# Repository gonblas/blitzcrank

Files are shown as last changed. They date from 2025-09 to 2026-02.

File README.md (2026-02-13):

Banner para Blitzcrank

# Blitzcrank

<p align="center">
  
  
</p>

## Descripción del proyecto

El proyecto **Blitzcrank** es un prototipo de **garra robótica móvil** diseñado para desplazarse en dos ejes (X e Y) mediante un sistema de rieles. Sobre este plano de movimiento, la garra puede **subir, bajar, abrir y cerrar**, lo que le otorga la capacidad de manipular objetos livianos dentro de un área determinada. El control se realiza manualmente a través de un **joystick de efecto Hall** y un conjunto de botones que permiten al usuario interactuar de manera sencilla e intuitiva.

Más allá de su valor como ejercicio técnico, el prototipo puede servir como base para múltiples aplicaciones: desde la simulación de procesos de **transporte y manipulación de piezas** hasta escenarios lúdicos como las clásicas máquinas de garras o sistemas recreativos de precisión, por ejemplo, un robot capaz de jugar al ajedrez moviendo las piezas en el tablero. De esta manera, Blitzcrank demuestra cómo la **tecnología robótica** puede adaptarse tanto a la **experimentación educativa** como a la **innovación aplicada** en proyectos más complejos.

<details>
  <summary><i>Objetivos del proyecto</i></summary>

  - **Objetivos primarios:**

    Se detallan a continuación aquellos objetivos de carácter obligatorio, necesarios para la validación del proyecto.

    - Implementar un sistema de rieles que permita el desplazamiento de la garra en los ejes X e Y.
    - Incorporar un mecanismo que posibilite el movimiento vertical de la garra para subir y bajar.
    - Desarrollar un sistema de control manual que garantice un manejo sencillo e intuitivo.
    - Integrar un actuador que permita abrir y cerrar la garra para tomar y soltar objetos.

  - **Objetivos secundarios:**

    A continuación se detallan aquellos objetivos de carácter opcional, sujetos a tiempo, materiales y costos disponibles.

    - Adaptar el sistema para manipular piezas de ajedrez en un tablero, garantizando precisión en la colocación.
    - Implementar un módulo de visión artificial que permita identificar la posición de las piezas en el tablero.
    - Integrar un algoritmo de inteligencia artificial que tome decisiones de juego y guíe automáticamente los movimientos de la garra.
    - Implementar una interfaz web que permita el manejo de la garra.

</details>

<details>
  <summary><i>Requerimientos del proyecto</i></summary>

  ##### Requerimientos Funcionales

  - **Requerimientos de Hardware:**

    - Debe contar con una interfaz física para mover la garra.
      - El sistema debe incluir unos botones dedicados al ascenso y descenso de la garra.
      - El sistema debe incluir un potenciómetro dedicado a la apertura y cierre de la garra.
      - El sistema debe incorporar un controlador para manejar los movimientos de la garra en los ejes X e Y.
      - El sistema debe incorporar un botón para manejar el cambio de modo físico y remoto.
    - Movimiento preciso de la garra.
      - El sistema de rieles debe permitir el movimiento de la garra en dos ejes cartesianos (X e Y), con un área mínima de trabajo de 15 cm x 15 cm.
      - El eje Z debe recorrer verticalmente al menos 5 cm para tomar y elevar piezas.
      - Se deben utilizar motores paso a paso para garantizar la posición exacta de la garra.
      - La garra debe ser capaz de levantar objetos de 50 gramos.
    - Todos los componentes deben estar ensamblados con fines de obtener un único sistema final compacto.

  - **Requerimientos de Software:**

    - Se debe desarrollar una interfaz de usuario capaz de controlar el sistema.
      - Desarrollar una interfaz que permita controlar manualmente la garra.
      - Implementar una interfaz web que permita seleccionar el modo de operación.
      - La interfaz debe ser intuitiva y clara, mostrando el estado del sistema y los errores en caso de que ocurran.
    - El software debe gestionar los límites de movimiento, deteniendo la garra para evitar daños mecánicos.

  ##### Requerimientos no funcionales

  Estos requerimientos no afectan en la funcionalidad del proyecto, por lo cual no se ve necesidad de hacer particular énfasis en la validación, pero que sí han sido tenidos en cuenta en el desarrollo.

  - Plataforma y desarrollo.
    - Utilizar una placa EDU-CIAA-NXP como centro de control del sistema, basada en el microcontrolador NXP LPC 4337.
    - Todo el firmware del EDU-CIAA debe ser desarrollado en lenguaje C.
  - Tiempo de ejecución: 16 semanas.
  - Presupuesto total de 600.000 ARS.
  - Documentación.
    - Documentar detalladamente el proceso de ensamblado del sistema.
    - Documentar el desarrollo del firmware, incluyendo rutinas de control e inicialización.
    - Documentar el diseño del esquemático y PCB, incluyendo conexiones, componentes y disposición de pines.
  - Garantizar la seguridad del usuario durante la operación del sistema, incluyendo protecciones físicas.

</details>

<details>
  <summary><i>Diagrama en bloques del sistema</i></summary>
  
  Diagrama en bloques inicial

</details>

<details>
  <summary><i>Tecnologías utilizadas</i></summary>
  <ol>

  <li>Hardware</li>
    <ul>
      <li>EDU-CIAA-NXP (LPC4337): placa central de control del sistema</li>
      <li>ESP-WROOM-32: módulo Wi-Fi para control remoto e interfaz web</li>
      <li>Motores paso a paso Nema17: movimiento en ejes X e Y</li>
      <li>Drivers DRV8825: control de motores paso a paso</li>
      <li>Motor DC GA12N20 + Driver DRV8833: accionamiento de polea</li>
      <li>Servomotor TowerPro MG90s: apertura y cierre de la garra</li>
      <li>Joystick analógico SYSPORT: control de movimiento X-Y</li>
      <li>Potenciómetro 10k: control analógico de la garra</li>
      <li>Fuente 12V 5A + Step Down XL4005: alimentación del sistema</li>
    </ul>

  <li>Firmware</li>
    <ul>
      <li>Lenguaje C para el firmware de la EDU-CIAA-NXP</li>
      <li>C++ con Arduino Framework para el firmware del ESP32</li>
      <li>PlatformIO como entorno de desarrollo del ESP32</li>
      <li>Comunicación UART entre EDU-CIAA y ESP32</li>
    </ul>

  <li>Interfaz web (ESP32)</li>
    <ul>
      <li>HTML, CSS y JavaScript servidos desde SPIFFS</li>
      <li>ESPAsyncWebServer para el servidor web embebido</li>
      <li>WebSockets para comunicación en tiempo real</li>
    </ul>

  <li>Diseño y fabricación</li>
    <ul>
      <li><a href="https://www.kicad.org/">KiCad</a>: diseño de esquemáticos y PCB</li>
      <li><a href="https://www.autodesk.com/products/fusion-360/overview">Fusion 360</a>: modelado 3D de estructura y garra</li>
      <li><a href="https://ultimaker.com/es/software/ultimaker-cura/">UltiMaker Cura</a>: preparación de piezas para impresión 3D</li>
    </ul>

  </ol>
</details>

---

## Materiales

| Componente | Cantidad | Función |
| --- | --- | --- |
| EDU-CIAA-NXP | 1 | Placa central que coordina motores, sensores y comunicación |
| ESP-WROOM-32 38 PINES | 1 | Control inalámbrico mediante Wi-Fi, interfaz web remota |
| Potenciómetro 10k Lineal 16mm | 1 | Entrada analógica para apertura de garra |
| Push Button Tact Switch 6x6mm | 3 | Entrada digital para abrir/cerrar garra |
| Joystick analógico SYSPORT | 1 | Control principal en ejes X e Y con pulsador integrado |
| Motor DC GA12N20 | 1 | Motorreductor para accionar polea |
| Driver Motor DC Puente H DRV8833 | 1 | Control de motor DC, inversión de giro y regulación por PWM |
| Servomotor TowerPro MG90s | 1 | Apertura y cierre de la garra |
| Motor paso a paso Nema17 17HS3404N | 2 | Movimiento de ejes X-Y |
| Driver DRV8825 | 2 | Controlador de motores paso a paso |
| Fuente de 12V 5A SIMALED LCS-1721-M1 | 1 | Fuente de alimentación externa para todo el sistema |
| Módulo Step Down XL4005 | 1 | Transformador de tensión |

---

## Diseño 3D

<details>
  <summary>Sistema completo</summary>
  <p align="center">
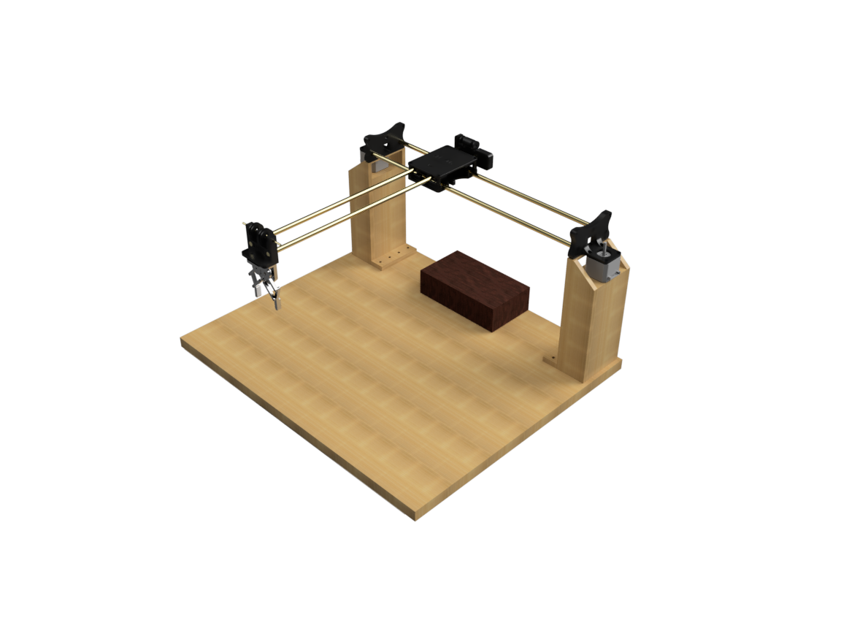
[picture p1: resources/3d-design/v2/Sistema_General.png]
    
  </p>
</details>

<details>
  <summary>Garra</summary>
  <p align="center">
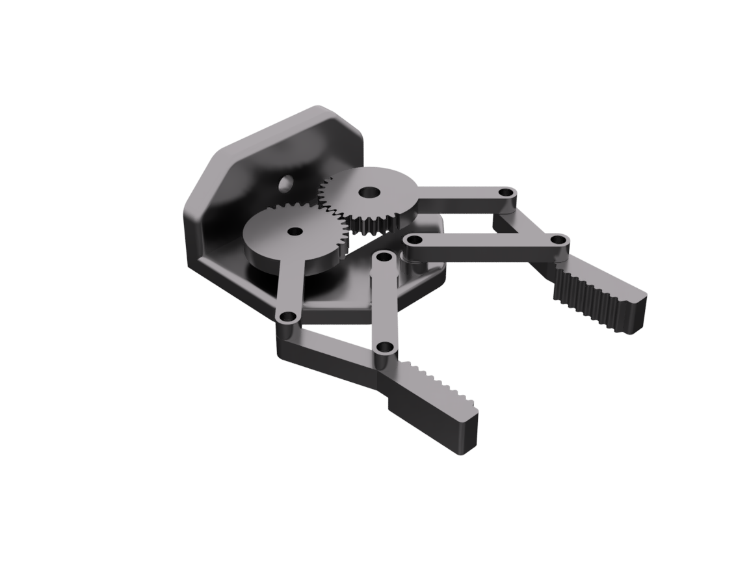
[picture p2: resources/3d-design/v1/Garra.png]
    
  </p>
</details>

<details>
  <summary>Sistema de poleas</summary>
  <p align="center">
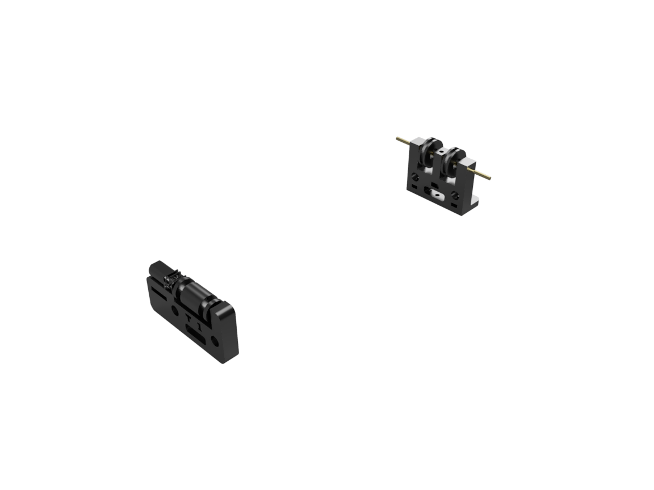
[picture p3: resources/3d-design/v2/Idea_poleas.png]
    
  </p>
</details>

<details>
  <summary>Controlador</summary>
  <p align="center">
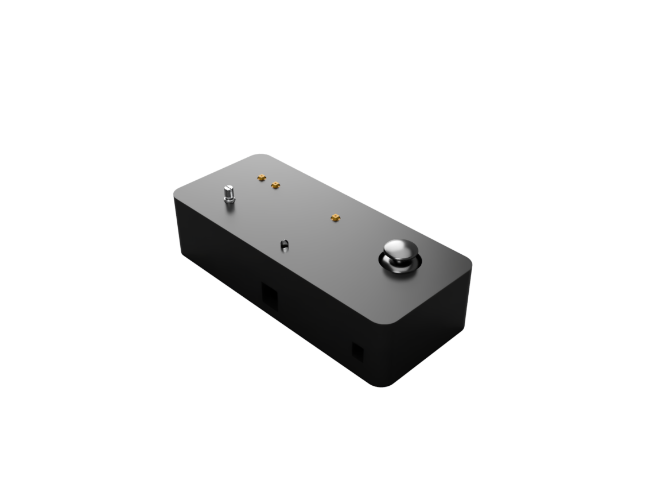
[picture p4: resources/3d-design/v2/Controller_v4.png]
    
    
  </p>
  <p align="center">
    
  </p>
</details>

<details>
  <summary>Eje Y</summary>
  <p align="center">
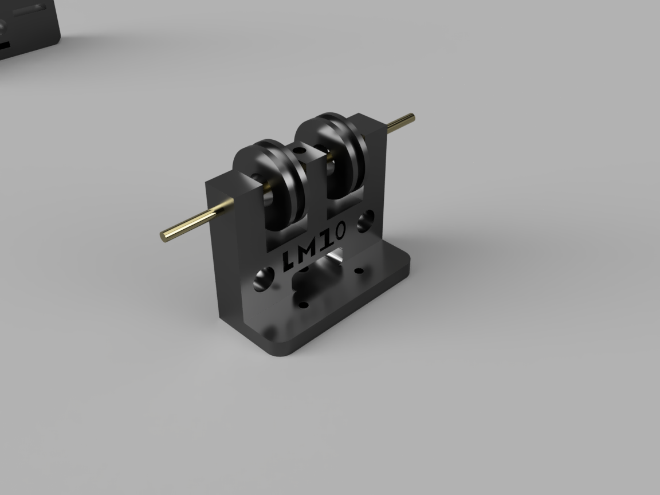
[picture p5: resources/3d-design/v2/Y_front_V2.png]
    
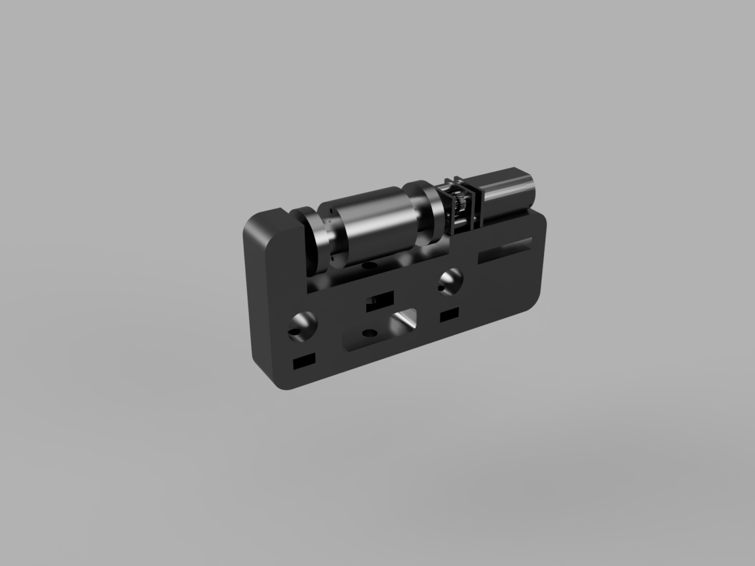
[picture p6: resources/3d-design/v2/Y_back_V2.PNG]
    
  </p>
</details>

---

## PCB

<details>
  <summary>Diseño del PCB</summary>
  <p align="center">
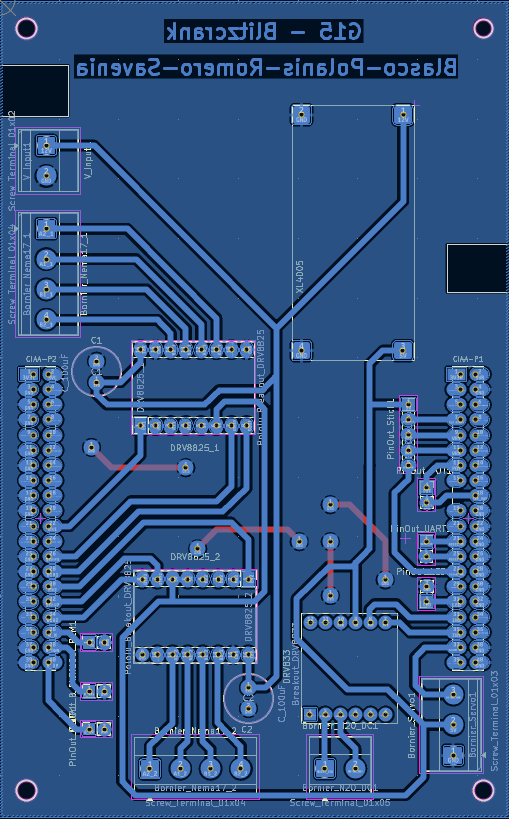
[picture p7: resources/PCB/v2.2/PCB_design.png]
    
  </p>
</details>

<details>
  <summary>PCB 3D</summary>
  <p align="center">
    
  </p>
</details>

<details>
  <summary>PCB Construído</summary>
  <p align="center">
    
    
  </p>
</details>

---

## Estructura del Proyecto

```
Blitzcrank/
│
├── build/                        # Archivos de compilación
├── docs/                         # Documentación y diagramas del proyecto
├── firmware/                     # Directorio principal del firmware
│   ├── mainboard/                # Firmware del controlador principal (LPC4337)
│   │   ├── .settings/            # Configuración del entorno de desarrollo
│   │   ├── app/                  # Aplicación principal del firmware
│   │   │   ├── drivers/          # Drivers de hardware (UART, SPI, I2C, GPIO, etc.)
│   │   │   ├── inc/              # Archivos de encabezado propios del proyecto
│   │   │   ├── out/              # Archivos de salida (build temporal, objetos, etc.)
│   │   │   └── src/              # Código fuente de la aplicación
│   │   │       └── main.c        # Punto de entrada del firmware
│   │   │
│   │   ├── examples/             # Ejemplos de uso de las distintas librerías
│   │   ├── libs/                 # Librerías externas o módulos reutilizables
│   │   ├── scripts/              # Scripts auxiliares para automatizar tareas del proyecto
│   │   ├── test/                 # Código de pruebas del hardware y validación de módulos
│   │   ├── .cproject             # Configuración del compilador (Eclipse)
│   │   ├── .gitignore            # Archivos ignorados por Git
│   │   ├── .project              # Configuración del proyecto (Eclipse)
│   │   ├── .travis.yml           # Integración continua (Travis CI)
│   │   ├── board.mk              # Configuración específica de la placa (paths, flags, etc.)
│   │   ├── LICENSE               # Licencia del proyecto
│   │   ├── Makefile              # Archivo principal de construcción del proyecto
│   │   ├── program.mk            # Reglas de programación/flasheo del firmware
│   │   ├── README.md             # Documentación general del firmware principal
│   │
│   └── esp-32/                   # Firmware del módulo ESP32
│       ├── src/                  # Código fuente principal (main.cpp)
│       │
│       ├── lib/                  # Librerías locales del proyecto
│       │   ├── WiFiManager/      # Manejo de conexión Wi-Fi y modo AP
│       │   ├── SpiffsManager/    # Gestión del sistema de archivos SPIFFS (lectura/escritura)
│       │   ├── Routes/           # Ruteo de peticiones HTTP y manejo del servidor web
│       │   └── UARTManager/      # Comunicación serial UART y sincronización de datos con la web
│       │
│       ├── data/                 # Archivos de la interfaz web que se suben al SPIFFS
│       │   ├── index.html
│       │   ├── style.css
│       │   └── script.js
│       │
│       ├── include/  
│       ├── lib/                  # Librerías externas (ESPAsyncWebServer, etc.)
│       ├── platformio.ini        # Configuración de PlatformIO
│       └── test/                 # Pruebas específicas del ESP
│
├── hardware/                     # Diseños de PCB, Esquemáticos, Diseños 3D
│   ├── pcb/                      # Diseños de PCB
│   ├── 3d-design/                # Diseños 3D
│   └── schematic/                # Circuitos esquemáticos
│
├── resources/                    # Documentación técnica y de apoyo
│   ├── 3d-design/                # Imágenes de los diseños 3D
│   ├── datasheets/               # Datasheets de los componentes utilizados
│   ├── manuals/                  # Manuales de módulos, sensores, devkits, etc.
│   ├── notes/                    # Apuntes técnicos, application notes, cálculos útiles
│   └── schematics/               # Esquemas de conexión, wiring y diagramas eléctricos
│
├── .clang-format                 # Configuración de estilo de código
├── .gitignore                    # Archivos ignorados por Git
├── LICENSE                       # Licencia del proyecto
├── README.md                     # Archivo actual
└── STYLE_GUIDE.md                # Convenciones de estilo del proyecto
```

Para ver las convenciones de nombres y estilo de código, consultar [STYLE_GUIDE.md](./STYLE_GUIDE.md)

---

## Flujo de funcionamiento del sistema

<p align="center">
  <a href="https://www.youtube.com/@BlitzcrankG15">
    
  </a>
</p>

<p align="center">
  <a href="https://www.youtube.com/watch?v=uDqSojhFeGg">
    
  </a>
  <a href="https://www.youtube.com/watch?v=HAsxXd6xPtw">
    
  </a>
</p>

---

## Autores

<ul>
  <li>
    <a href="https://www.linkedin.com/in/gonblas/">
      
    </a>
    <a href="https://github.com/gonblas">
      
    </a>
    <strong>Blasco, Gonzalo</strong>
    <br clear="right"/>
  </li>

  <li>
    <a href="https://www.linkedin.com/in/ivanpolanis/">
      
    </a>
    <a href="https://github.com/ivanpolanis">
      
    </a>
    <strong>Polanis, Iván Valentín</strong>
    <br clear="right"/>
  </li>

  <li>
    <a href="https://www.linkedin.com/in/mateo-romero-dev/">
      
    </a>
    <a href="https://github.com/mateoromero-dev">
      
    </a>
    <strong>Romero, Mateo</strong>
    <br clear="right"/>
  </li>

  <li>
    <a href="https://www.linkedin.com/in/manuel-savenia-b38639363/">
      
    </a>
    <a href="https://github.com/manuSavenia">
      
    </a>
    <strong>Savenia, Manuel</strong>
    <br clear="right"/>
  </li>
</ul>

## Coordinador

<ul>
  <li>
    <a href="https://www.linkedin.com/in/joaquín-chanquía-a747a1291/">
      
    </a>
    <a href="https://github.com/joacochanquia">
      
    </a>
    <strong>Joaquín Chanquía</strong><br />
    <em>Ayudante – Taller de Proyecto I</em>
    <br clear="right"/>
  </li>
</ul>

---

## Licencia

Este proyecto se distribuye bajo la licencia [GPL](LICENSE).

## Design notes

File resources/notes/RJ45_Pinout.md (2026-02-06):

# Controller RJ-45 Pinout

| Color | Nombre (es) | Función / Notas | Pin PONCHO |
| --- | --- | --- | --- |
| 🔵 Azul | Joystick Y | Señal analógica del eje Y del joystick | VRY |
| 🟡 Amarillo | Joystick X | Señal analógica del eje X del joystick | VRX |
| 🟠 Naranja  | Bit de conexión | Línea digital para handshake / estado de conexión | ON |
| 🟢 Verde | LED | Alimentación / señal para LED indicador | L |
| 🟣 Violeta  | Potenciómetro | Entrada analógica de potenciómetro | POT |
| ⚫ Negro | Botón Down | Pulsador para acción "bajar" | DWN(S) |
| ⚪ Blanco | Botón Switch Mode | Pulsador para cambiar modo | MD |
| ◻️ Gris | Botón Up | Pulsador para acción "subir" | UP |

# USB

| Color | Pin PONCHO |
| --- | --- |
| Naranja | 5V+ |
| Negro | BTN_DWN |

Notas:

- Verifica con un multímetro/continuidad antes de conectar si no estás seguro del cableado.

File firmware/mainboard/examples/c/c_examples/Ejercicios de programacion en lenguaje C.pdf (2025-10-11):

# Ejercicios de programación en lenguaje C

Estos programas pueden probarlos primero en la PC usando http://cpp.sh/ o http://onlinegdb.com/ (elegir lenguaje C y presionar run).

Los usuarios de Linux Pueden usar la plantilla de Embedded IDE "gcc-exec" y probarlo en sus propias PC. Los de Windows hay que instalar más herramientas para compilar C para PC asi que usen el compilador on line.

# Ejercicios básicos de C

### 1. Suponga que una variable declarada como

uint16_t temperatura_sensor;

contiene la salida de un sensor de temperatura con una resolución de 10 bits y un rango de 0°C a 800 °C.Esto es, el valor temperatura_sensor = 0 corresponderá a la medida de 0 °C mientras que temperatura_sensor = 1023 corresponderá a la medida de 800 °C.

Sería deseable disponer de una nueva variable: temperatura_grados que almacene la medida directamente en grados para poder procesarla y mostrarla por UART directamente.

a. Escriba el programa que transforma el valor entregado por el sensor a grados Celcius y lo almacena en temperatura_grados.
b. Pruebe distintos valores de temperatura_sensor y conviértalos a temperatura_grados.

Imprima los valores por UART. Por ejemplo
temperatura_sensor = 0 --> temperatura_grados = 0°C temperatura_sensor = 128 --> temperatura_grados = 100°C temperatura_sensor = 512 --> temperatura_grados = 400°C temperatura_sensor = 1023 --> temperatura_grados = 800°C
c. Sabiendo que el rango de la variable temperatura_sensor admite valores menores que 0 y mayores que 1023, busque una solución para detectar estos casos e indicarle al usuario de que hay una falla en el sensor.

2. Operadores.
a. Indique el resultado de las siguientes expresiones:

(1 >2) || (1<2)
(1>2) && 3
1 + 2 / 3 * 4 – 5
b. Considerando: int a=1, b=2, c=3; diga cuánto valen cada una de las siguientes expresiones:

a<b && c<b
a<b && c
a<=c || b>c
a!=b-1 || b>2 || a+c>2

### 3. Bucles 1

Realice una tabla utilizando printf() en la UART con el siguiente encabezado:

x | x al cuadrado | x al cubo
a) complete con valores enteros de x entre 0 y 20 utilizando un bucle while.
b) complete con valores enteros de x entre 0 y 20 utilizando un bucle for.
c) complete con valores reales de x entre 0 y 10, con incrementos de 0.5 utilizando un bucle while.
d) complete con valores reales de x entre 0 y 10, con incrementos de 0.5 utilizando un bucle for.

Nota: utilice el caracter '\t' que realiza la función de tab para ordenar correctamente las tablas en la Terminal. Revisar si lo soporta la terminal serie que utiliza.

### 4. Bucles 2

Realice los siguientes "dibujos" en la Terminal Serie parametrizados según el valor de N y M, según corresponda (usar #define para N y M).

a)
*
*
*
*
(N filas)

b)
*
**
***
****
(N filas)

c)
1
22
333
4444
(N filas)

d)
1
12
123
1234
(N filas)

e)
*******
*******
*******
(N filas x M columnas)
f) El cuadrado:
*******
* | *
* | *
*******
(N filas x M columnas)
g) El triángulo:
*******
* *
* *
*
(N filas, con N impar)

# Ejercicios de C con Arreglos (vectores o matrices)

Resolver los siguientes utilizando índices de arreglos

5. Realice nuevamente el ejercicio 3 pero esta vez utilice los arreglos x[], x2[] y x3[] para almacenar primero los valores correspondientes de x, x al cuadrado y x al cubo, respectivamente.
Luego repita la tabla a partir de los arreglos anteriores.
6. Dado un arreglo de 40 caracteres que contiene un string a elección, realizar un programa que cuente la cantidad de caracteres y la cantidad de mayúsculas del string e imprima el resultado usando índice para recorrer el arreglo.
7. Realice un programa que copie el string contenido en el arreglo Texto1 al arreglo Texto2 cambiando todas las letras mayúsculas por minúsculas y luego imprima un string debajo del otro en pantalla. Ambos arreglos son de 30 caracteres.

### 8. Dado cuatro arreglos de 20 caracteres: Texto1, Mayu, Minu y Noletra, realizar un

programa que a partir del string a elección almacenado en Texto1, genere 3 strings:
Uno en Mayu con todas las mayúsculas, otro en Minu todas las minúsculas y otro en Noletra con todos los caracteres que no sean letras.
Finalmente deberá imprimir los 4 strings en líneas sucesivas dentro de llaves o corchetes.
9. Dados dos arreglos de 50 caracteres Tx1 y Tx2 que contiene strings a elección, realizar un programa que imprima los strings y luego concatene el string contenido en Tx2 al de Tx1. Finalmente Imprimir el string resultante contenido en Tx1. Todos los strings deberán imprimirse dentro de llaves o corchetes.

### 10. Dado un arreglo de 30 caracteres que contiene un string a elección, realizar un

programa que cuente e imprimir a la cantidad de vocales de cada tipo. Usar la estructura switch.

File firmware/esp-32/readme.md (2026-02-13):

# Firmware ESP32 - Control Web de Garra

Este firmware permite el control remoto de una garra robótica a través de una interfaz web. El sistema crea un servidor web en el ESP32 que sirve una página de control desde la cual se puede manejar la garra de forma inalámbrica.

## Estructura del Proyecto

```
esp-32/                       # Firmware del módulo ESP32
├── src/                      # Código fuente principal (main.cpp)
│   └── main.cpp
│
├── lib/                      # Librerías locales del proyecto
│   ├── WiFiManager/          # Manejo de conexión Wi-Fi y modo AP
│   │   └── config.h
│   ├── SpiffsManager/        # Gestión del sistema de archivos SPIFFS (lectura/escritura)
│   ├── Routes/               # Ruteo de peticiones HTTP y manejo del servidor web
│   └── UARTManager/          # Comunicación serial UART y sincronización de datos con la web
│
├── data/                     # Archivos de la interfaz web que se suben al SPIFFS
│   ├── index.html
│   ├── style.css
│   └── script.js
│
├── platformio.ini            # Configuración del entorno PlatformIO (placa, librerías, etc.)
├── readme.md                 # Este archivo
└── test/                     # Pruebas específicas del firmware (unit tests o integración)
```

## Requisitos

Para usar este firmware necesitas tener instalado **PlatformIO** en Visual Studio Code.

### Instalación de PlatformIO

1. Abre Visual Studio Code
2. Ve a la pestaña de Extensiones (Ctrl+Shift+X)
3. Busca "PlatformIO IDE"
4. Instala la extensión oficial

**Enlace directo**: [PlatformIO IDE Extension](https://marketplace.visualstudio.com/items?itemName=platformio.platformio-ide)

## Configuración WiFi

El sistema puede funcionar en dos modos:
- **Modo Access Point (AP)**: El ESP32 crea su propia red WiFi
- **Modo Cliente**: El ESP32 se conecta a una red WiFi existente

Para configurar el modo de funcionamiento, edita el archivo `lib/WiFiManager/config.h` donde puedes establecer:
- SSID y contraseña de la red WiFi
- Modo de operación (AP o Cliente)

## Pasos para Probar el Funcionamiento

1. **Abrir PlatformIO**: Ve a la extensión de PlatformIO en VS Code
2. **Subir archivos web**: En la pestaña **Platform** → hacer clic en **Upload Filesystem Image**
3. **Limpiar proyecto**: En la pestaña **General** → hacer clic en **Full Clean**
4. **Compilar**: En la pestaña **General** → hacer clic en **Build**
5. **Subir y monitorear**: En la pestaña **General** → hacer clic en **Upload and Monitor**

> **Nota**: El **Full Clean** solo es necesario la primera vez para evitar errores de compilación.

## Acceso a la web

Para utilizar el control remoto, se deben seguir los siguientes pasos:

1. **Conectarse a la red Wi-Fi del sistema:**

   Desde una computadora o dispositivo móvil, conectarse a la red Wi-Fi generada por el ESP32 con los siguientes datos:

   - **Nombre de red (SSID):** `blitzcrank`
   - **Contraseña:** `garra12345`

2. **Acceder a la interfaz web:**

   Una vez establecida la conexión Wi-Fi, abrir un navegador web y acceder a la siguiente dirección: [http://192.168.4.1](http://192.168.4.1)

   Al ingresar esta dirección, se cargará la página web correspondiente al control remoto del sistema.

## Flujo de Trabajo para Modificaciones

### Solo cambios en archivos web (data/)
- Ejecutar únicamente: **Upload Filesystem Image**

### Solo cambios en código (src/, lib/)
- Ejecutar: **Build** → **Upload and Monitor**

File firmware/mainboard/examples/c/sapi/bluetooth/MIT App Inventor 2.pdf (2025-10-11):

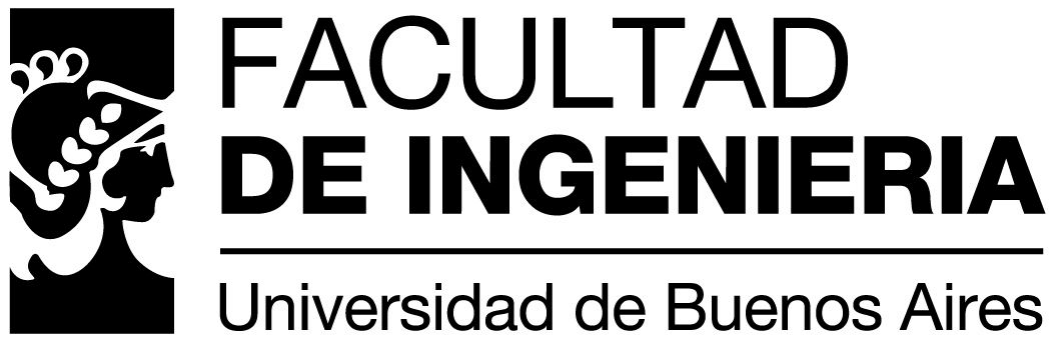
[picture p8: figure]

## Carrera de Especialización en Sistemas Embebidos (CESE) de la FI-UBA

### 8. Protocolos de comunicación en Sistemas Embebidos

MIT App Inventor 2

Profesores:
- Esp. Ing. Eric Pernia.
- Dr. Ing. Pablo Gómez.

“MIT App Inventor 2”
por Esp. Lic. Agustin Bassi, se distribuye bajo una Licencia Creative Commons Atribución-CompartirIgual 4.0 Internacional.

## Licencia

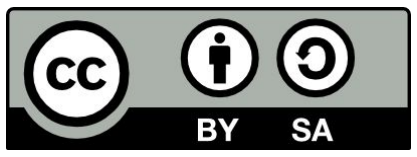
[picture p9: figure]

Para realizar una aplicación en Android para probar la comunicación con la EDU-CIAA-NXP vamos a utilizar APP Inventor, que es una herramienta sencilla para desarrollar aplicaciones Android evitando utilizar las herramientas típicas las cuales consisten en lenguaje de programación Java, XML, emulación virtual y el entorno de desarrollo Android Studio. (https://developer.android.com/studio/)

APP Inventor es un desarrollo de Google que permite programar aplicaciones para Android mediante programación gráfica. Posteriormente, el proyecto fue retomado por el MIT y ahora es conocido como MIT App Inventor 2.

MIT App Inventor 2 es una herramienta para desarrollo on line por lo que requiere conexión permanente a Internet.

## Introducción

Paso 1

Tener una cuenta en Gmail
En https://accounts.google.com/ se puede crear una cuenta. Si ya se tiene cuenta, este paso es innecesario.

Paso 2

Ir a la página de MIT App Inventor 2
Dirigirse a http://appinventor.mit.edu/explore/front.html Allí inicia todo!

## Configuración APP Inventor 2

Paso 3 - Iniciar MIT App Inventor

Dirigirse a http://appinventor.mit.edu/explore/index-2.html y dar clic en “Create Apps”.

## Configuración APP Inventor 2

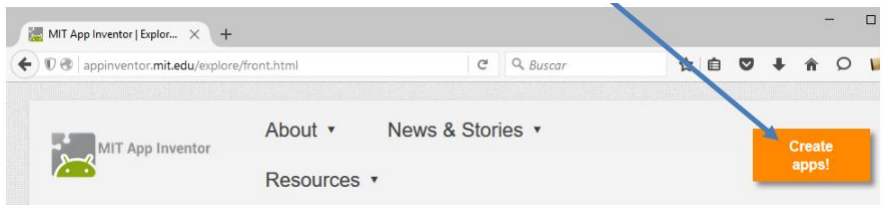
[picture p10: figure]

Paso 4 - Acceder a APP Inventor 2 con la cuenta de Google.

## Configuración APP Inventor 2

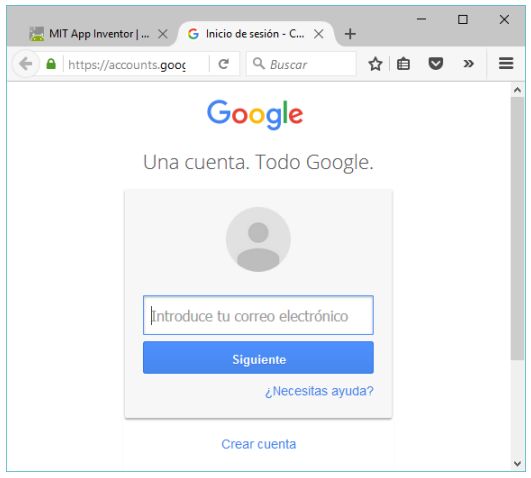
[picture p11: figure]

Paso 5 - Pantalla de inicio APP Inventor.

Al ser la primera vez, no se tienen proyectos en la cuenta.

## Configuración APP Inventor 2

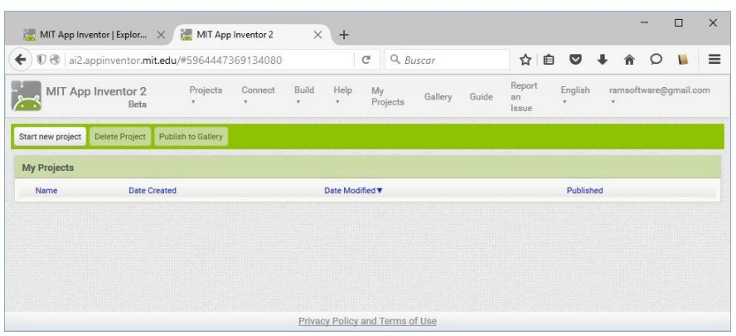
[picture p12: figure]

Paso 6 - Cambiar idioma en APP Inventor

Si es de preferencia, cambiar el idioma a Español.

## Configuración APP Inventor 2

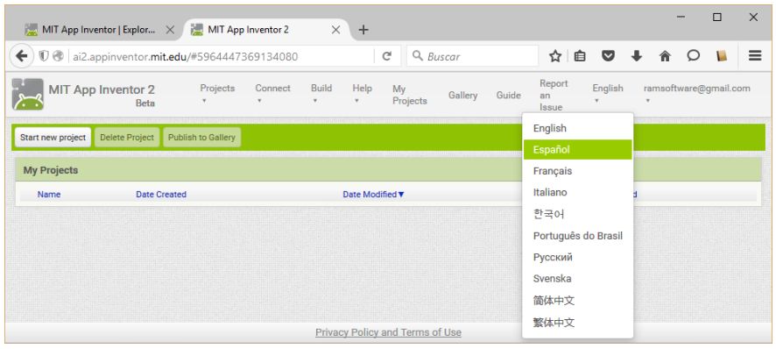
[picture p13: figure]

Paso 7 - Aceptar la información.
Tildar la opción “Do not show Again” para que no vuelva a aparecer este cartel nuevamente.

## Configuración APP Inventor 2

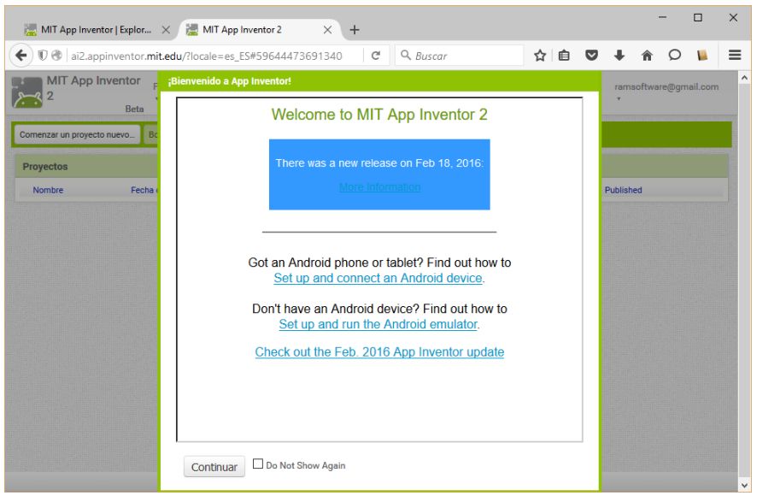
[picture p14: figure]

Paso 8 - Fin de la configuración

Bienvenido a APP Inventor 2 !!!

## Configuración APP Inventor 2

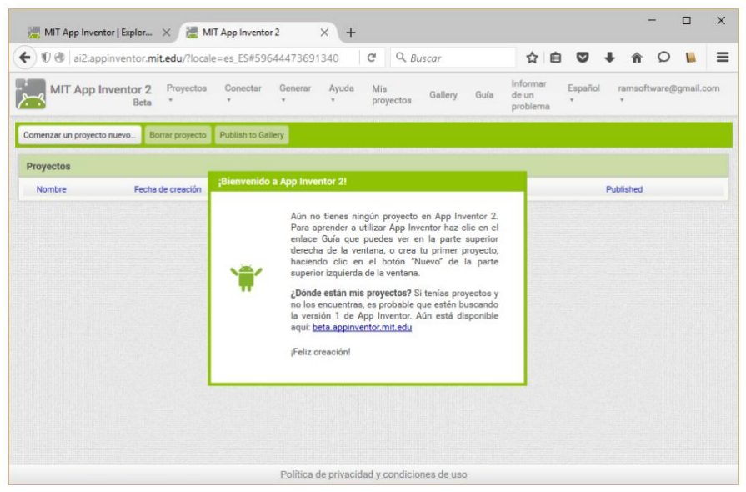
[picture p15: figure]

APP Inventor 2 permite debuggear la aplicación creada directamente en el celular.

Para que esto sea posible es necesario instalar una aplicación de APP Inventor 2 que se encuentra en el Play Store de Google.

Descargar la aplicación y dar los permisos necesarios para que pueda ejecutarse.

## Instalar aplicación APP Inventor 2

## Instalar aplicación APP Inventor 2

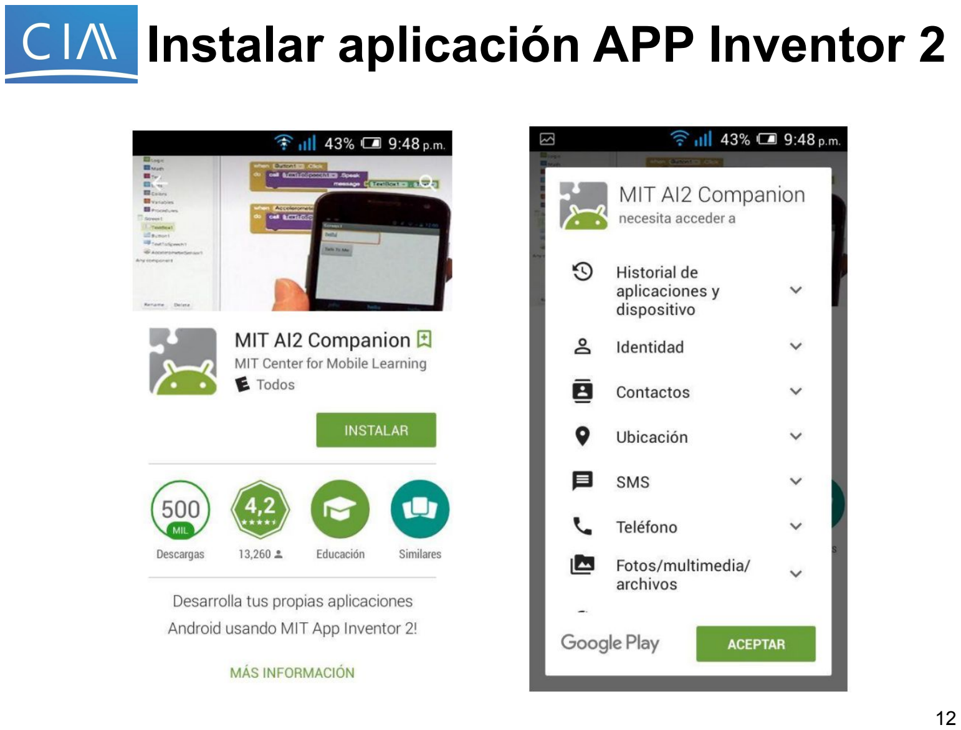
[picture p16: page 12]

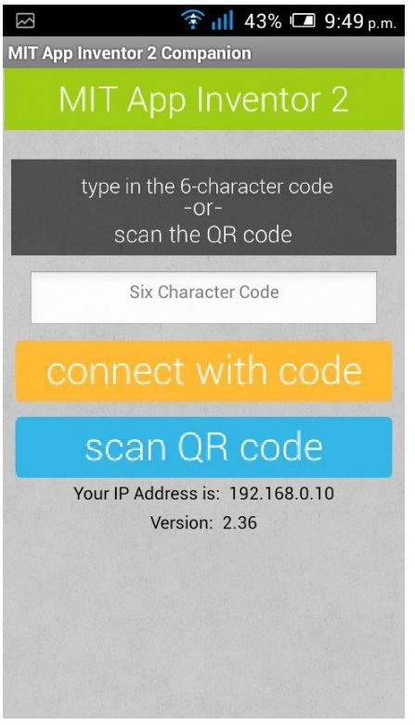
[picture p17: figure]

La aplicación MIT App
Inventor 2 Companion va a
permitir vincular el
desarrollo realizado dentro de la web con el
smartphone personal.

Mediante el escaneo de un
código QR o la escritura del código provisto en la web, automáticamente se carga
la aplicación desarrollada en el smartphone.

## Instalar aplicación APP Inventor 2

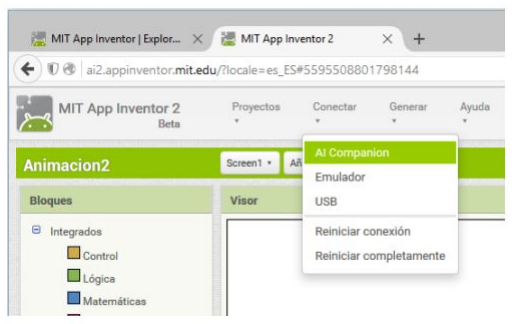
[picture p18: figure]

Dentro de la web de App
Inventor 2, seleccionar
“Conectar” y luego “AI
Companion”.

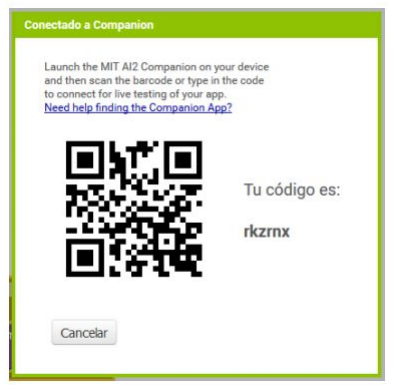
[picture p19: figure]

Esto genera el código QR
que debe ser escaneado
desde la aplicación de APP Inventor previamente
instalada en el smartphone.

## Instalar aplicación APP Inventor 2

# ¿Preguntas?

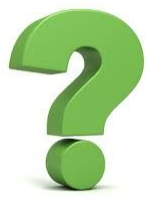
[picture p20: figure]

## Consultas:

ericpernia@gmail.com
elpablogomez@gmail.com
sergiordj@gmail.com

# ¡Muchas gracias!

- http://www.bolanosdj.com.ar/MOVIL/LENGUAJES/Usan

do-MIT-App-Inventor-2.pdf (http://www.bolanosdj.com.ar/MOVIL/LENGUAJES/Usando-MIT-App-Inventor-2.pdf)

- http://ai2.appinventor.mit.edu/

## Bibliografía

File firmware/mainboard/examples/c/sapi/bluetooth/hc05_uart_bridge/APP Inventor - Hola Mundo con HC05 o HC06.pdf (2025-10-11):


# Carrera de Especialización en Sistemas Embebidos (CESE) de la FI-UBA

## 8. Protocolos de comunicación en Sistemas Embebidos

## APP Inventor - Hola Mundo con HC05 o HC06

Profesores:
- Esp. Ing. Eric Pernia.
- Dr. Ing. Pablo Gómez.

## “APP Inventor - Hola Mundo!” por Esp. Lic. Agustin Bassi, se distribuye bajo una Licencia Creative Commons Atribución-CompartirIgual 4.0

Internacional.

# Licencia


## El objetivo será crear una aplicación Android que tenga comunicación con la EDU-CIAA-NXP mediante el módulo

Bluetooth HC05 o HM10.

Los materiales necesarios serán.

- EDU-CIAA-NXP.
- Módulo HC05 o HM10.
- Cables de conexión entre EDU CIAA y HC05.
- Cuenta creada en APP Inventor.
- Smartphone con Android.

# Introducción

# Cargar programa en EDU CIAA

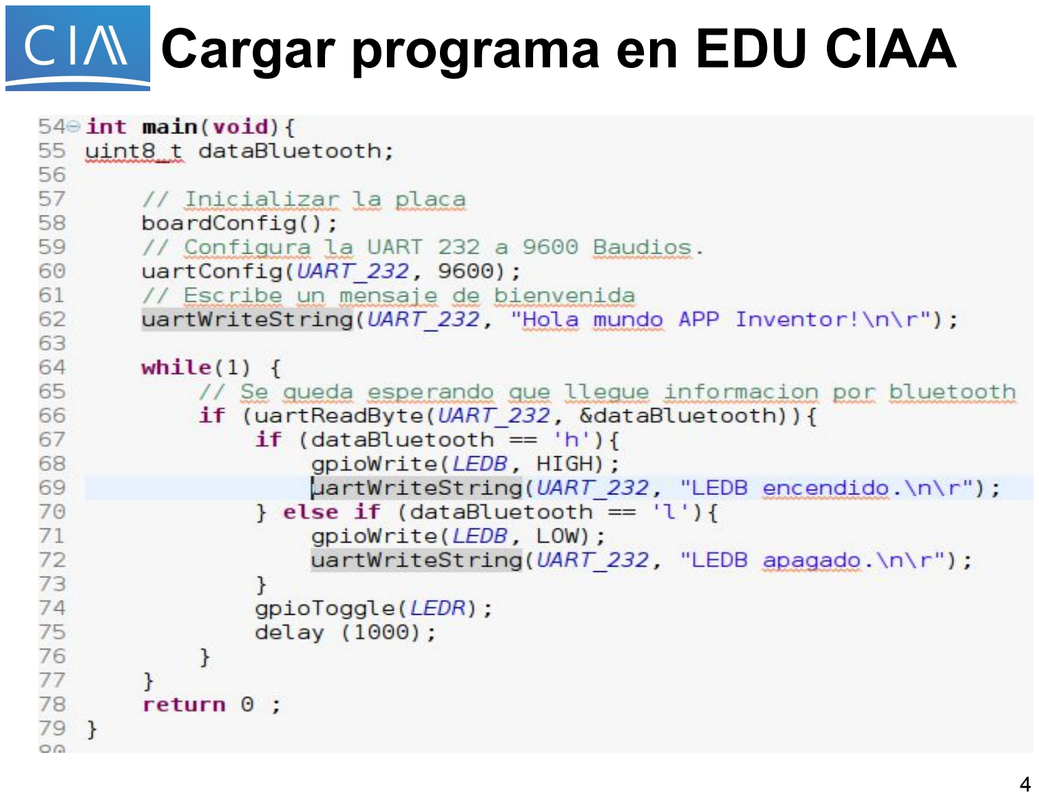
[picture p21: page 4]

## Comenzar creando un proyecto nuevo con el botón “Comenzar

nuevo proyecto”.

Ingresar como nombre Estación Metereológica.

# Hola Mundo App Inventor 2!

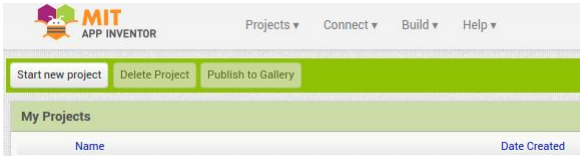
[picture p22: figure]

Al iniciar el proyecto, se verá una ventana como esta.

# Hola Mundo App Inventor 2!

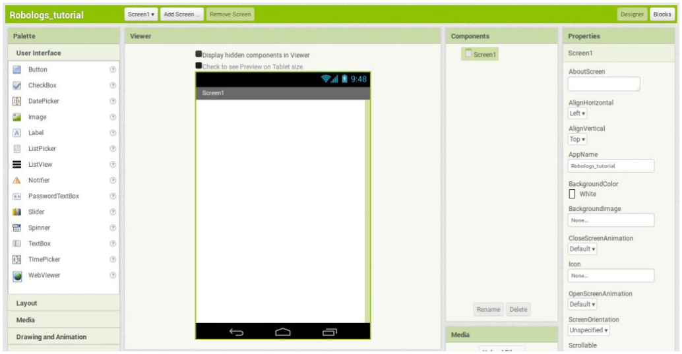
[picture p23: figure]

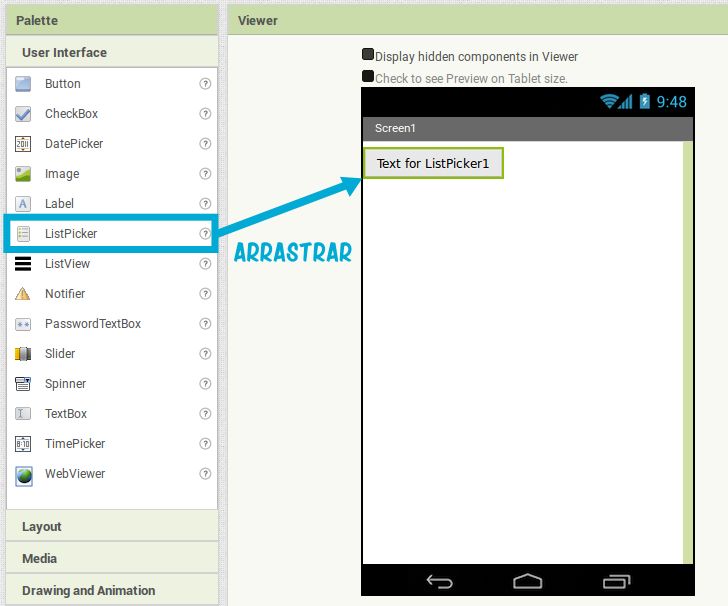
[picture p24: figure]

Empezar yendo a

Palette y buscar el

elemento List Picker.

Se trata de menú

desplegable, que se

programa para que

muestre los

dispositivos Bluetooth

cercanos y se conecte

a uno. Arrastrarlo

hasta la pantalla.

# Hola Mundo App Inventor 2!

A la derecha, en el menú Properties, cambiar el texto

del List Picker. Escribir “Dispositivos”.

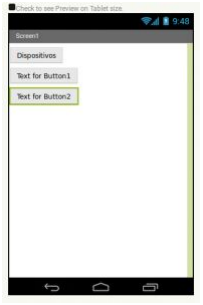
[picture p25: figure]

Volver al menú Palette y añadir dos elementos de tipo

Button a la aplicación, de la misma forma que se

colocó el List Picker.

Seleccionar cada uno de los botones y cambiarles el

nombre. A uno llamar “Encender LED” y al otro

“Apagar LED”. Con un botón se encenderá el LEDB y

con el otro se apagará.

# Hola Mundo App Inventor 2!

La comunicación entre la APP y el sistema embebido debe ser

bidireccional. Se deben agregar los objetos destinados a la

recepción de datos.

Agregar desde el menú | Palette->User Interface | un objeto del tipo

Label y en sus propiedades escribirle el texto “Información

Recibida”.

Como último objeto visual, debajo del Label agregar un TextBox.

# Hola Mundo App Inventor 2!

Lo que se ha añadido hasta ahora son componentes visibles. El usuario puede verlos e interactuar con ellos. Pero hay otro tipo de componentes, llamados non-visible components, que sirven para activar algunas funcionalidades como el Giroscopio, la antena WiFi o Bluetooth.

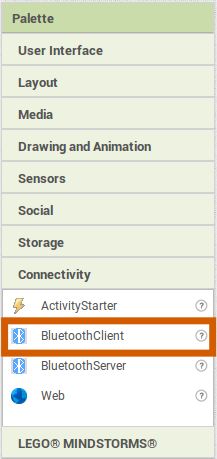
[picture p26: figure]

Para poder conectar con la CIAA se necesita que la aplicación pueda usar la antena Bluetooth.

Ir a Palette->Connectivity y arrastrar Bluetooth Client a la pantalla.

# Hola Mundo App Inventor 2!

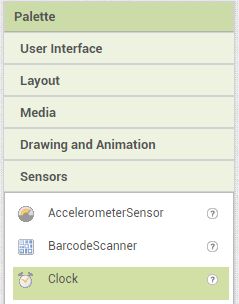
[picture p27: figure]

El último objeto necesario a agregar es

un timer que chequee si hay información

disponible proveniente del sistema

embebido.

Esto se realiza desde | Palette->Sensors
y arrastrando un objeto | Clock.

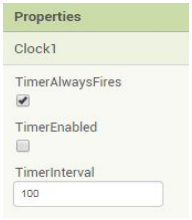
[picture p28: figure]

En las propiedades del clock setear que

se dispare cada 100 ms y que arranque

deshabilitado.

# Hola Mundo App Inventor 2!

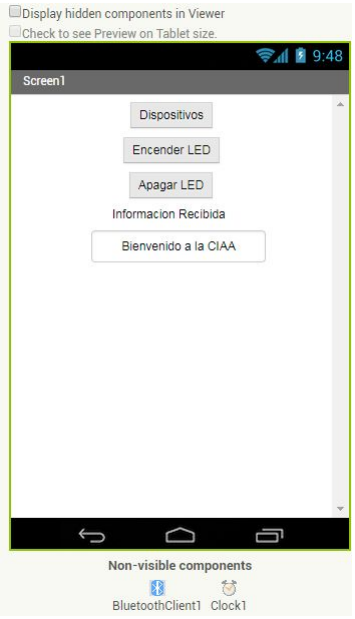
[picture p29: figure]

A esta altura, la aplicación debería lucir como en la imagen.

Hasta aquí el diseño. Es hora de configurar cada uno de los componentes.

Arriba a la derecha hay dos botones juntos: Design y Blocks. El primero abre la ventana de diseño, que permite colocar todos los
componentes de la aplicación. Blocks abre una ventana para programar los bloques.

# Hola Mundo App Inventor 2!

Lo primero es programar el menú desplegable. A la derecha, seleccionar ListPicker1 y se abrirá un menú en el que aparecen los bloques relacionados con este objeto.
Hay que programar en el desplegable dos cosas: qué debe hacer ANTES de seleccionar una opción del menú desplegable y DESPUÉS de seleccionar una.

Antes de seleccionar una opción,

inicializar una lista con los nombres

de todos los dispositivos Bluetooth

que hay cerca.

Si el móvil tiene la comunicación

Bluetooth activada, ListPicker1

deberá establecer los nombres de

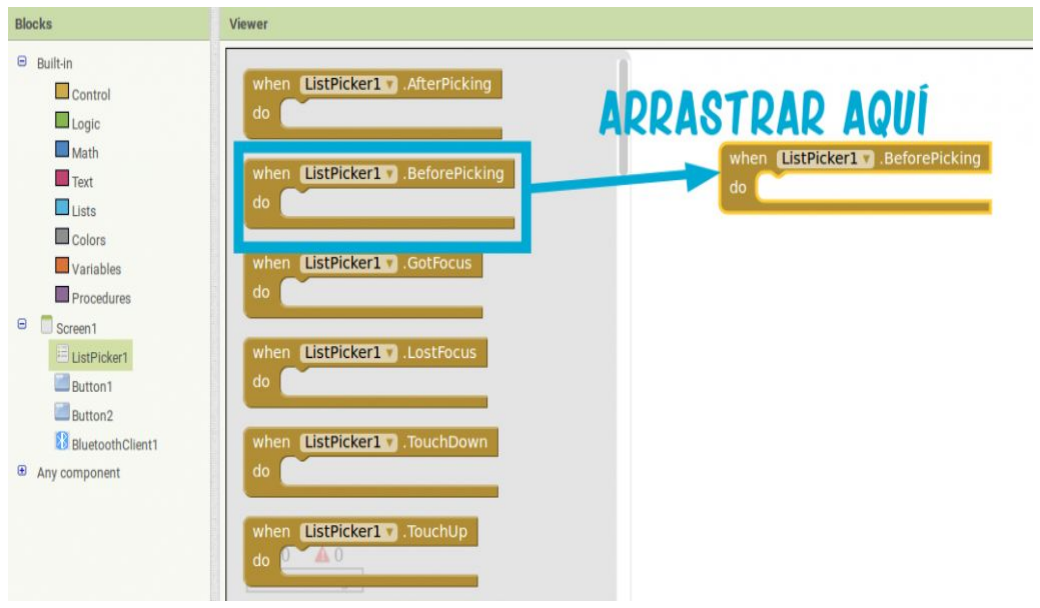
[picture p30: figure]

los dispositivos cercanos como elementos de la lista.

Dentro del menú de bloques de | ListPicker1 arrastrar. BeforePicking | al espacio
en blanco.

# Hola Mundo App Inventor 2!

# Hola Mundo App Inventor 2!

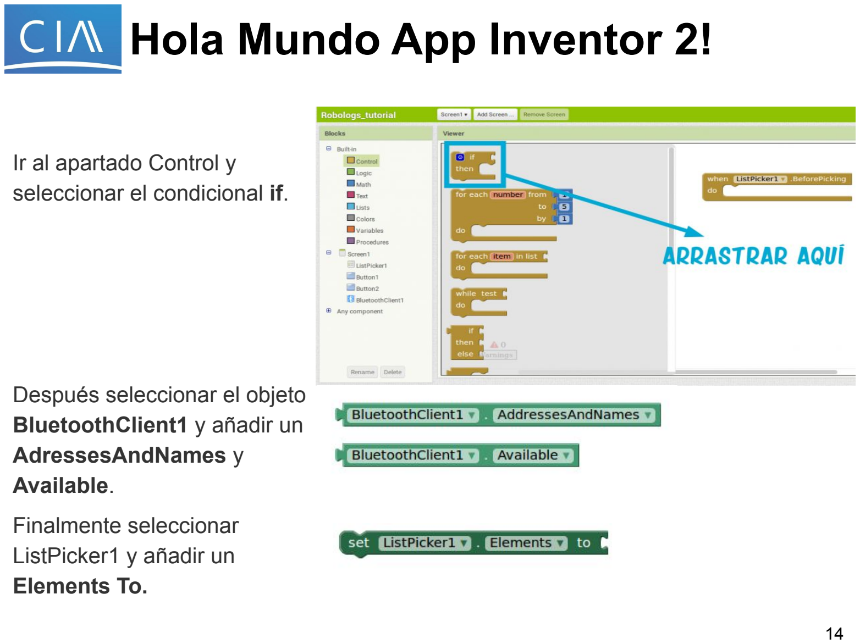
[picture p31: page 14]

Ir al apartado Control y
seleccionar el condicional if.

Después seleccionar el objeto
BluetoothClient1 | y añadir un
AdressesAndNames | y
Available.

Finalmente seleccionar
ListPicker1 y añadir un
Elements To.

# Hola Mundo App Inventor 2!


Montar todos los bloques anteriores para que queden así.

Luego programar a ListPicker1 para que se conecte a la dirección que el usuario seleccione en la lista. Una vez conectado, habilitar el timer para recibir información desde el sistema embebido. El resultado final debería ser así.

Al inicio de la aplicación deshabilitar el campo de texto donde se va a mostrar la info recibida así no se puede escribir en ese campo.

Si la aplicación recibe un dato enviado desde el sistema embebido lo debe mostrar en el campo de texto. Para chequear si la aplicación recibió datos, es necesario chequear periódicamente mediante el timer si hay datos disponibles en el objeto de conexión BluetoothClient1

# Hola Mundo App Inventor 2!


Finalmente configurar Button1 y Button2 para que al pulsarlos se envíe un texto a la dirección Bluetooth conectado.

# Hola Mundo App Inventor 2!


Corresponde al
ASCII ‘h’

Corresponde al
ASCII ‘l’

# Hola Mundo App Inventor 2!


Al final, el programa debería verse así:

# Hola Mundo App Inventor 2!


Escanear el código QR desde la APP Inventor en el smartphone y probar la aplicación.

Recordar habilitar el Bluetooth en el smartpone antes de escanear el código QR

# ¿Preguntas?


# Consultas:

## ericpernia@gmail.com elpablogomez@gmail.com sergiordj@gmail.com

# ¡Muchas gracias!

## - http://ai2.appinventor.mit.edu/

## - http://www.bolanosdj.com.ar/MOVIL/LENGUAJES/Usan

do-MIT-App-Inventor-2.pdf (http://www.bolanosdj.com.ar/MOVIL/LENGUAJES/Usando-MIT-App-Inventor-2.pdf)

## - http://codeweek.eu/resources/spain/guia-iniciacion-app-

## inventor.pdf (http://codeweek.eu/resources/spain/guia-iniciacion-app-inventor.pdf)

## - https://robologs.net/2015/10/29/tutorial-de-arduino-bluet

ooth-y-android-2-crear-una-app-con-mit-inventor/ (https://robologs.net/2015/10/29/tutorial-de-arduino-bluetooth-y-android-2-crear-una-app-con-mit-inventor/)

# Bibliografía

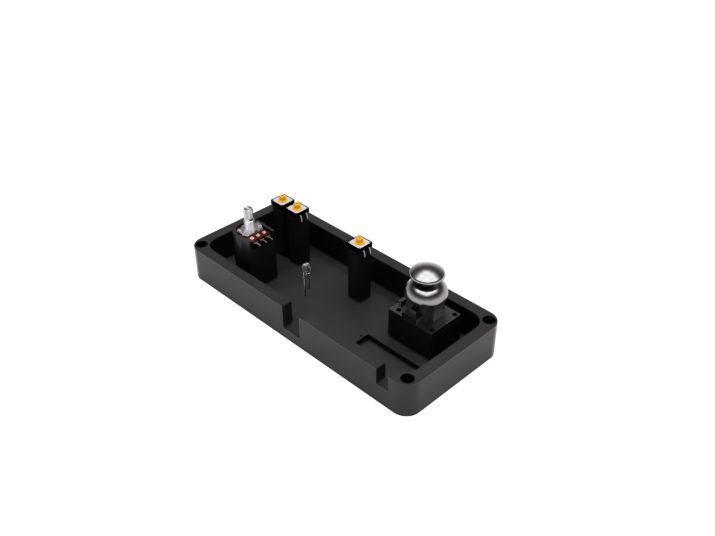
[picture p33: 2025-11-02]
resources/3d-design/v2/Control_Adentro.PNG

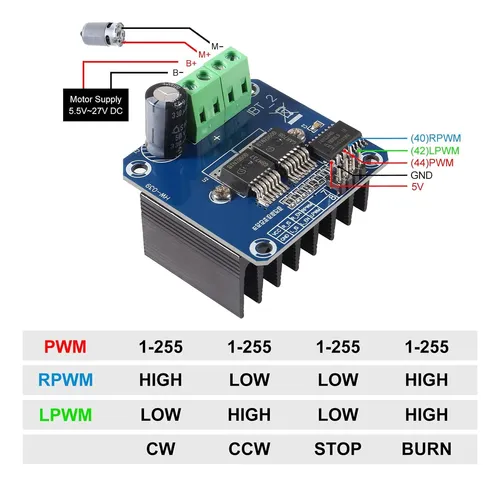
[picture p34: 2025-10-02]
resources/notes/Bts7960 - Pinout.webp

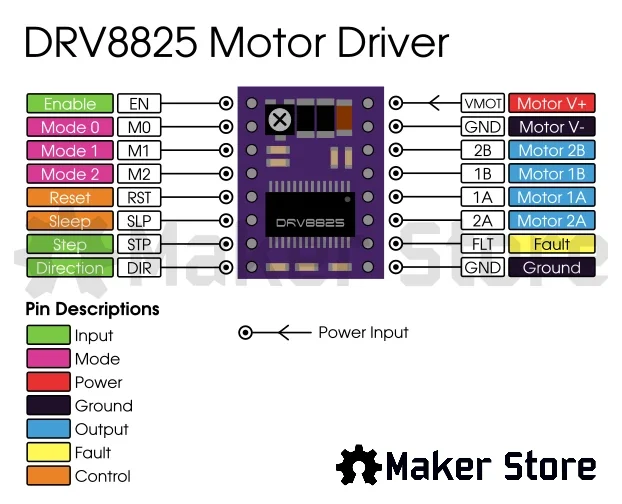
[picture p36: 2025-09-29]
resources/notes/DRV8825 - Pinout.webp

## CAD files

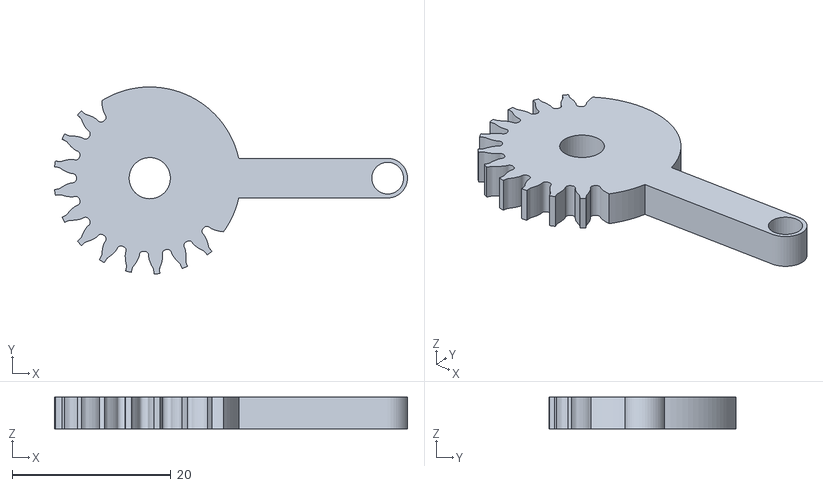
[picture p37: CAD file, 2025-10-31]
hardware/3d-design/v2/claw/gear_right_v2.stl
44.5 x 23.6 x 4.00

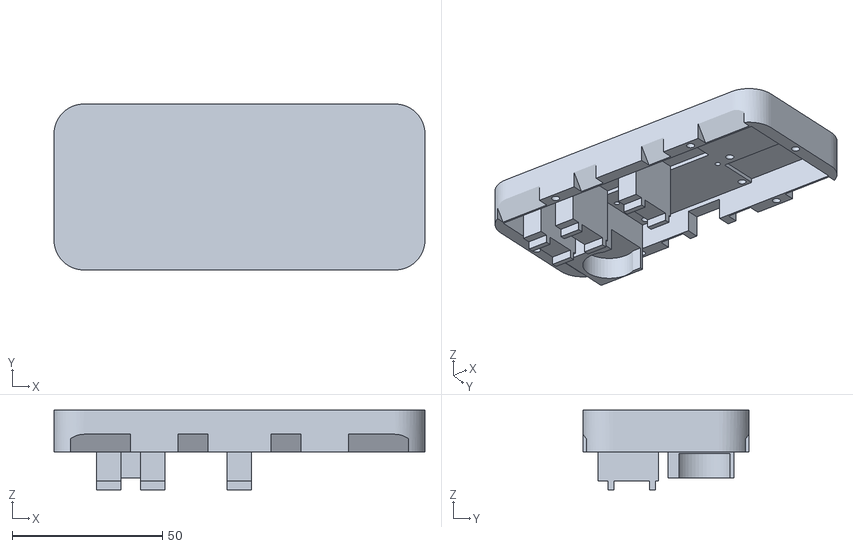
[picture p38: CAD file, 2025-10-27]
hardware/3d-design/v2/controller/Controller-bottom-v3.stl
123.4 x 55.2 x 26.5

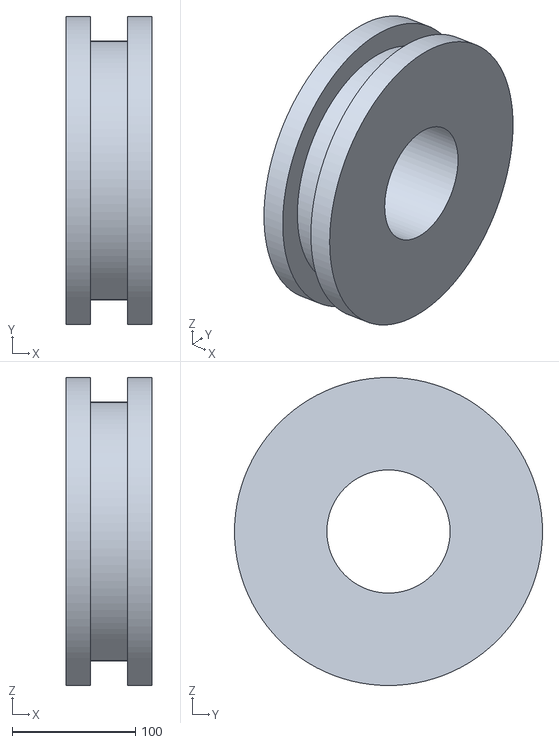
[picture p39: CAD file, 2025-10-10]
hardware/3d-design/v2/structure/Polea.stl
70.0 x 250.0 x 250.0

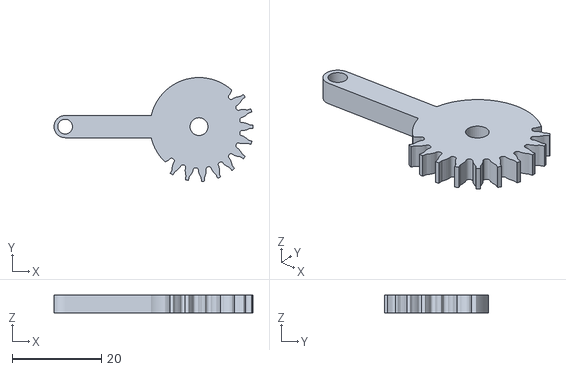
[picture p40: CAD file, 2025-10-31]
hardware/3d-design/v2/claw/gear_left_v2.stl
44.6 x 23.3 x 4.00

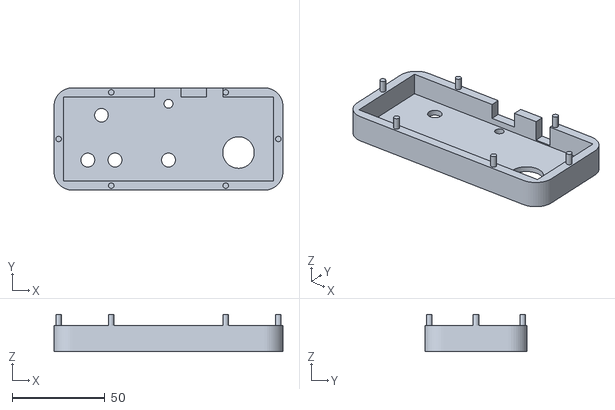
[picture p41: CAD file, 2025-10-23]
hardware/3d-design/v2/controller/Controller-Top-V2.stl
123.4 x 55.2 x 20.0

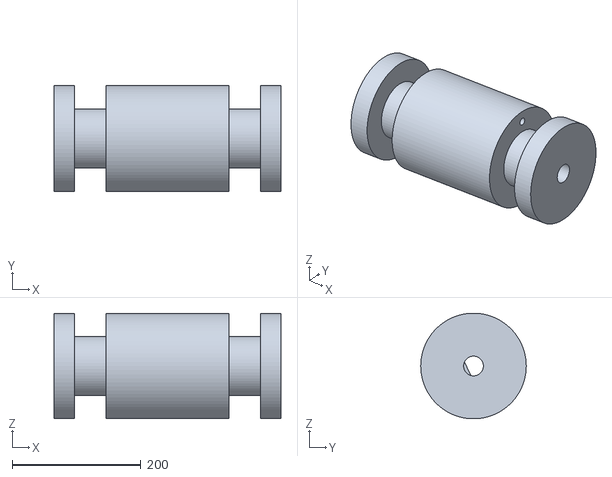
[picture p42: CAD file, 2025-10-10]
hardware/3d-design/v2/structure/Tambor.stl
352.3 x 163.9 x 163.7

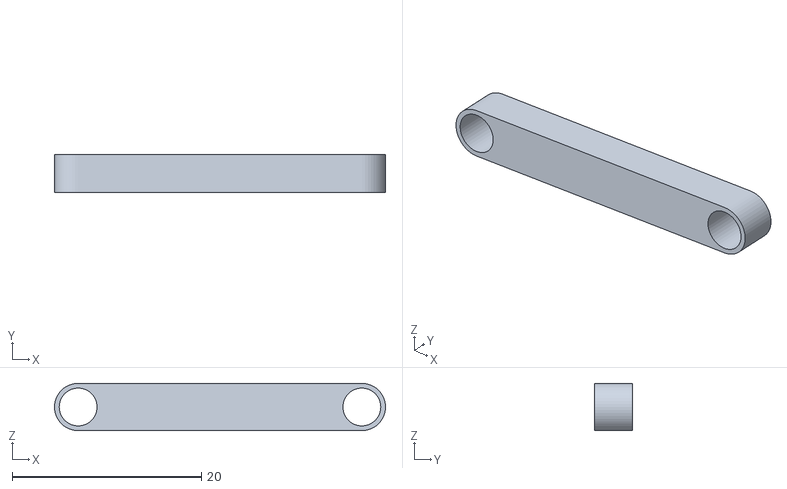
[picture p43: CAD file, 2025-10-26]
hardware/3d-design/v2/claw/arm_right_v2.stl
35.0 x 4.00 x 5.00

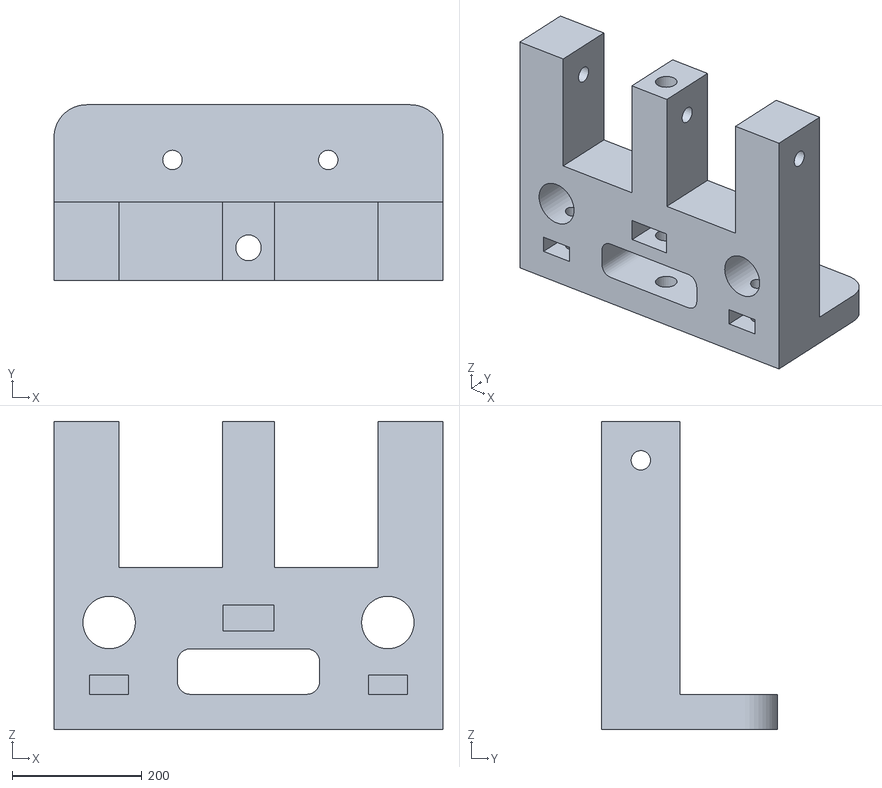
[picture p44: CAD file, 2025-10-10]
hardware/3d-design/v2/structure/Y-front-v2.stl
599.3 x 270.4 x 475.0

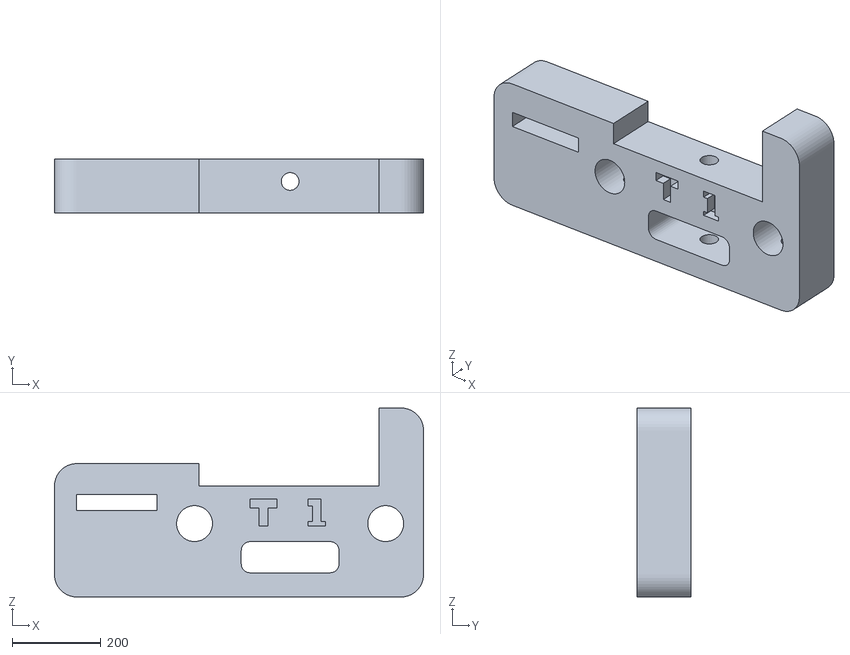
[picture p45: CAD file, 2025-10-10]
hardware/3d-design/v2/structure/Y-back-v2.stl
830.0 x 120.4 x 425.0

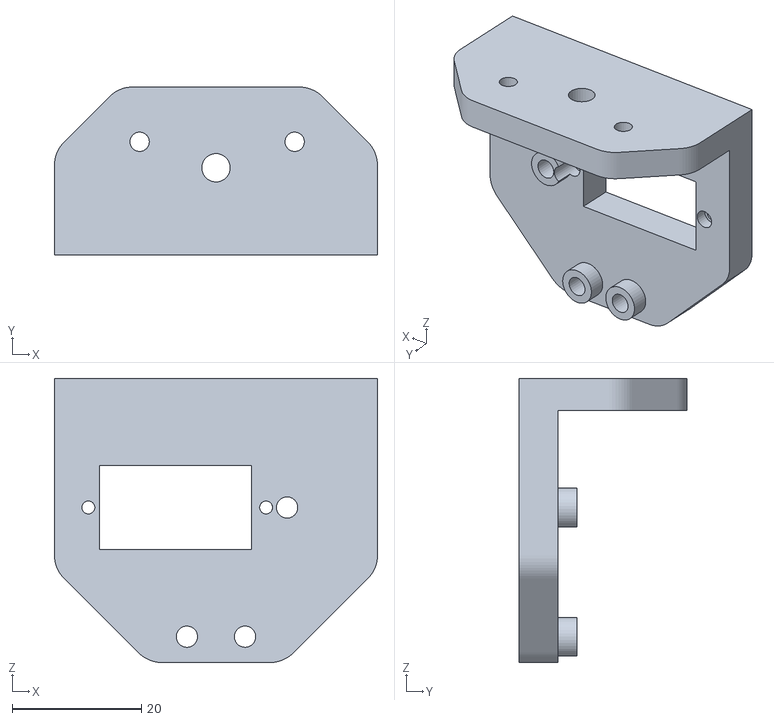
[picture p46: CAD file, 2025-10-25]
hardware/3d-design/v2/claw/Soporte Garra v3.stl
50.0 x 26.0 x 44.0

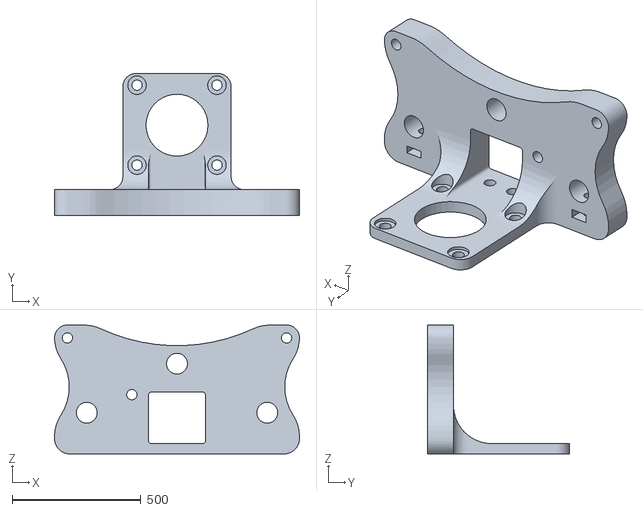
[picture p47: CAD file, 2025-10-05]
hardware/3d-design/v2/structure/X_support_R.stl
950.0 x 550.0 x 500.0

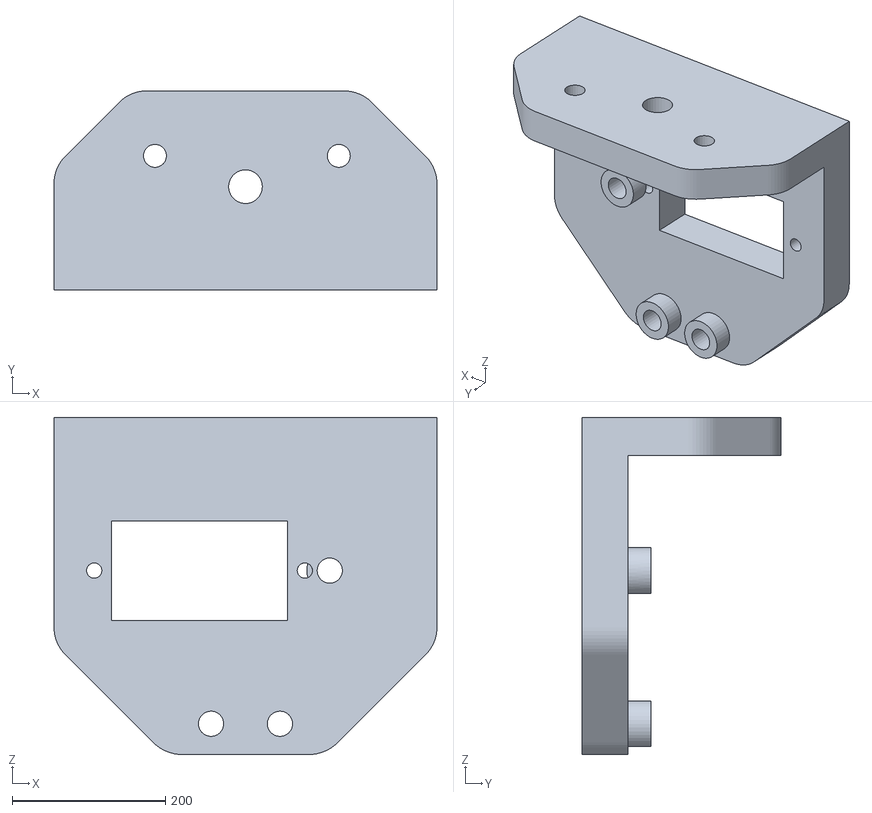
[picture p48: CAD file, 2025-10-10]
hardware/3d-design/v2/claw/Soporte Gancha v2.stl
500.0 x 260.0 x 440.3

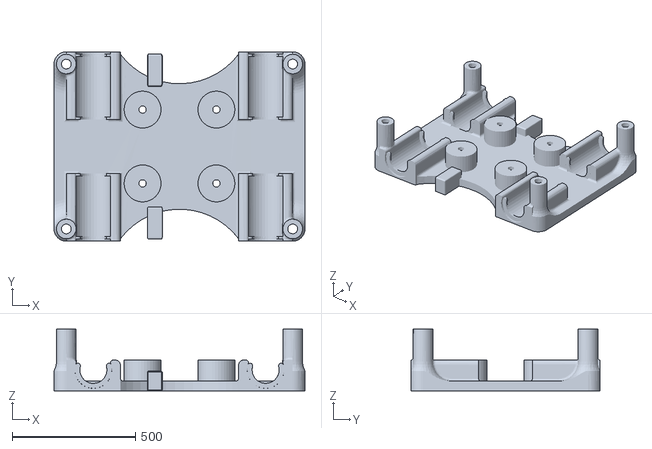
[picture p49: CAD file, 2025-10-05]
hardware/3d-design/v2/structure/Bottom_XY_clamshell_V2.stl
1020.0 x 770.0 x 250.5

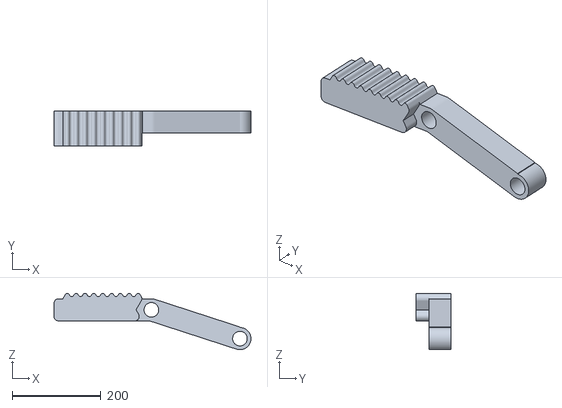
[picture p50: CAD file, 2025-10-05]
hardware/3d-design/v2/claw/jaw_left.stl
445.0 x 80.0 x 127.3

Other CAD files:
hardware/3d-design/v2/structure/Top_XY_clamshell_V4.stl
hardware/3d-design/v2/claw/jaw_right.stl
hardware/3d-design/v1/claw/base_plate.stl
hardware/3d-design/v1/structure/Y_Back.stl
hardware/3d-design/v1/structure/Y_Front.stl
hardware/3d-design/v2/controller/Controller-bottom-V2.stl

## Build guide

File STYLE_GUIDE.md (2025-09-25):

## Archivos y directorios

- Los **nombres de directorios** deben estar en minúsculas y separados por guiones si son compuestos:
  - `src/`, `firmware/`, `build/`, `docs/`
- Los **archivos C/C++** usan snake_case:
  - `motor_driver.c`, `sensor_utils.cpp`
- Los **archivos de cabecera** usan el mismo nombre que el `.c/.cpp` pero con `.h`:
  - `motor_driver.h`
- Los **archivos de scripts** (Python, Bash) usan snake_case y extensión correspondiente:
  - `build_firmware.sh`, `run_tests.py`

## Clases y funciones

- Las **clases** usan CamelCase:
  - `MotorController`, `SensorArray`
- Las **funciones** usan snake_case:
  - `read_sensor()`, `set_motor_speed()`
- Constantes y macros en mayúsculas con guiones bajos:
  - `#define MAX_SPEED 100`

## Otros

- Variables globales limitadas y con prefijo `g_` si es necesario.
- Variables estáticas con prefijo `s_`.
- Evitar nombres ambiguos: usar nombres descriptivos.
- Archivos de prueba van en `test/` con sufijo `_test.c`.cds

## Mensajes de commit

Para mantener consistencia y claridad en el historial de Git, todos los commits deben seguir este formato:

### Formato general

```
<tipo>[alcance opcional]: <mensaje conciso>

<cuerpo opcional más detallado>
```

- **tipo:** indica el tipo de cambio
- **alcance (opcional):** carpeta, módulo o componente afectado
- **mensaje conciso:** máximo 50 caracteres, en presente
- **cuerpo:** máximo 72 caracteres por línea; explicar **qué y por qué**, no cómo

### Tipos recomendados

| Tipo | Descripción | Ejemplo |
| --- | --- | --- |
| `feat` | Nueva funcionalidad | `feat(motor): add PID control` |
| `fix` | Corrección de bug | `fix(sensor): calibrate temperature reading` |
| `docs` | Cambios en documentación | `docs: add naming conventions section` |
| `style` | Formato, espacios, indentación, sin cambiar funcionalidad | `style: apply clang-format to src/` |
| `refactor` | Cambios de código que no afectan funcionalidad | `refactor(firmware): simplify main loop` |
| `test` | Añadir o modificar pruebas | `test(driver): add max speed test` |
| `chore` | Tareas de mantenimiento | `chore: update build dependencies` |

### Buenas prácticas

1. Mensaje conciso en presente: “agrega”, “corrige”, “elimina”.
2. Evitar abreviaturas oscuras o mensajes ambiguos.
3. Relacionar el commit con **módulos o directorios** si aplica (`motor/`, `sensor/`, `test/`).
4. Separar cambios funcionales de estilo: nunca mezclar `feat` con `style`.

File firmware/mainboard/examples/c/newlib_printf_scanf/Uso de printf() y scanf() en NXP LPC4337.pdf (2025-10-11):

# Uso de printf() y scanf() en el microcontrolador NXP LPC4337

# Biblioteca newlib, printf() y scanf() completas o reducidas

La biblioteca estándar de C llamada newlib, que incluye el compilador arm-none-eabi del NXP LPC4337 (el microcontrolador que tiene al EDU-CIAA-NXP o la CIAA-NXP) permite utilizar printf() y scanf() con el microcontrolador.

La biblioteca newlib permite ser compilada en 2 versiones. Una versión completa y una versión reducida nombrada newlib nano.

Si se utiliza newlib nano printf() y scanf() no permiten imprimir o recibir valores en punto flotante (float).

Para desactivar newlib nano y que compila la new lib completa en la carpeta app del proyecto, el archivo config.mk poner:

USE_NANO=n

Por defecto viene en y (que si use nano).

De esta manera podemos poner en un programa:

printf( "Pi vale aproximadamente %f\n", 3.14 );

scanf() y printf() utilizan la UART2 del microcontrolador (UART_USB en la sAPI) como entrada/salida estándar por lo que no se debería reconfigurar la UART2, la está configurada por defecto a 115200 baudios. Esto se hace en el startup del microcontroaldor.

Entonces un programa básico que utilice printf() puede ser simplemente:

#include "sapi.h" // <= Biblioteca sAPI, o alternativamente puede

| // usarse board.h que incluye LPCOpen
int main( void )
{
printf( "Pi vale aproximadamente %f\n", 3.14 ); while( TRUE );
return 0;
}

NOTA:

Si usan printf() en un microcontrolador van a notar que no imprime directamente (envía directo a la UART) si no que lo hace a través de un buffer el cual se envía a la salida estándar, en nuestro caso la UART.

En un programa en la PC si no hay \n este buffer se envía a la salida estándar cuando se llama a la función fflush(), la cual por ejemplo se llama cuando termina el programa.

En embebidos el programa no termina nunca (por el while(1)), entonces hay que forzar el fflush de 2 formas:

1. Llamando a la función fflush():

fflush(stdout);

2. Con \n dentro del texto de printf()

printf( "Hola\n" );

# Uso de memorias del microcontrolador

Se puede probar compilar el mismo programa con la opción USE_NANO en "y" y también en "n" y observar la diferencia de ocupación de memorias.

### Con newlib nano

text | data | bss | dec | hex filename
11460 | 300 | 76 | 11836 | 2e3c app/out/app.elf

En este caso printf() no imprime los valores float %f, pero no da errores, simplemente los ignora.

### Con newlib completa

text | data | bss | dec | hex filename
28992 | 2676 | 152 | 31820 | 7c4c app/out/app.elf

En este caso printf() funciona con todas sus características.

Para comprender esos números, todos están en bytes y representan:

- text - contiene el código compilado y datos de sólo lectura (read-only) de la aplicación (el valor de bytes está en decimal).
- data - shows the read-write data in your application (el valor de bytes está en decimal).
- bss - Muestra los datos inicializados con 0 ('bss' y 'common') en la aplicación (el valor de bytes está en decimal).
- dec - Total = 'text' + 'data' + 'bss' (el valor de bytes está en decimal).
- hex - El valor de bytes en hexadecimal equivalente al de 'dec'.

Esto típicamente se interpreta como:

- Consumo de FLASH de la aplicación equivale a text + data.
- Consumo de RAM de la aplicación equivale a data + bss.

Más información en: http://www.support.code-red-tech.com/CodeRedWiki/FlashRamSize

Como puede observarse, newlib completa ocupa muchos más recursos.

# Uso de printf() y scanf()

## printf()

Las funciones de la familia printf producen una salida de acuerdo a format como se describe abajo. Printf y vprintf escriben su salida a stdout, el flujo de salida estándar. fprintf y vfprintf escriben su salida al stream de salida dado. sprintf, snprintf, vsprintf y vsnprintf escriben a una cadena de caracteres str.

### Prototipo o declaración

int printf( const char *format, ... );

### Ejemplos

printf("Strings:\n");
const char* s = "Hello";
printf("\t.%10s.\n\t.%-10s.\n\t.%*s.\n", s, s, 10, s);

printf("Characters:\t%c %%\n", 65);

printf("Integers\n");
printf("Decimal:\t%i %d %.6i %i %.0i %+i %u\n",1,2,3,0,0,4,-1); printf("Hexadecimal:\t%x %x %X %#x\n", 5, 10, 10, 6); printf("Octal:\t%o %#o %#o\n", 10, 10, 4);

printf("Floating point\n");
printf("Rounding:\t%f %.0f %.32f\n", 1.5, 1.5, 1.3); printf("Padding:\t%05.2f %.2f %5.2f\n", 1.5, 1.5, 1.5); printf("Scientific:\t%E %e\n", 1.5, 1.5); printf("Hexadecimal:\t%a %A\n", 1.5, 1.5);

### Los caracteres % (especificaciones de conversión)

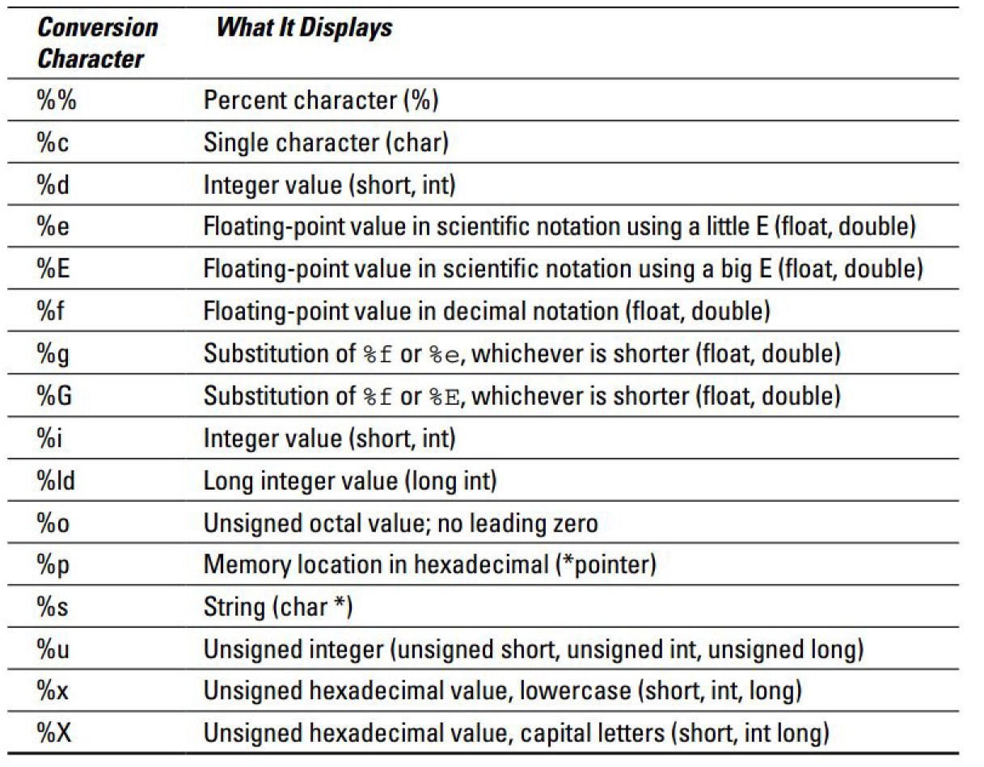
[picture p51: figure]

### Más información

- http://es.tldp.org/Paginas-manual/man-pages-es-1.28/man3/printf.3.html
- https://es.cppreference.com/w/c/io/fprintf

## scanf()

La familia scanf de funciones busca en la entrada según un formato como se describe más adelante. Este formato puede contener especificadores de conversión; los resultados de tales conversiones, si las hay, se guardan donde apunten los argumentos punteros. La
función scanf | lee la entrada del flujo de entrada estándar stdin, fscanf | lee su entrada del
puntero a FILE flujo, y sscanf | lee su entrada de la cadena de caracteres a la que apunte str.

### Prototipo o declaración

int scanf( const char *format, ... );

### Ejemplo

char text[50];
printf( "Ingrese un texto y presione enter:\r\n" ); scanf( "%s", text );
printf( "El texto ingresado es: %s\r\n", text );

### Los carcateres % (especificaciones de conversión)

%c para indicar entrada de un caracter
%d para indicar entrada de un entero
%f para indicar entrada de un flotante
%s para indicar entrada de un string

### Sugerencias para el uso de scanf()

- Antes de usar scanf, imprimir con printf() indicando al usuario qué tipo de dato o información debe ingresar.
- Ingresar de a un dato por vez. Será mejor que cada llamado a scanf() sea para ingresar un dato, evitar el ingreso múltiple.
- Para ingresar texto, indicar el máximo de caracteres que scanf() debe aceptar, así no almacena en zonas inapropiadas.

### Más información

- http://es.tldp.org/Paginas-manual/man-pages-es-1.28/man3/scanf.3.html
- https://es.cppreference.com/w/c/io/fscanf

# Ejemplo con scanf() y printf()

#include "sapi.h" // <= Biblioteca sAPI, o alternativamente puede // usarse board.h que incluye LPCOpen

// La UART_USB se inicializa en el startup del microcontrolador a // 115200 baudios para salida y entrada estandar.

// Recordar en config.mk poner USE_NANO=n (usar newlib completa // en lugar de newlib nano) para tener soporte de flotantes en // printf(), sin embargo, esto causa que el programa ocupe MUCHA // mas RAM y FLASH.

int main( void )
{
printf( "Pi vale aproximadamente %f\r\n", 3.14 );

char text[50];
int num;

printf( "Ingrese un texto y presione enter:\r\n" ); scanf( "%s", text );
printf( "El texto ingresado es: %s\r\n", text );

printf( "Ingrese un numero y presione enter:\r\n" ); scanf( "%d", &num );
printf( "El numero ingresado es: %d\r\n", num );

while( TRUE );

return 0;
}

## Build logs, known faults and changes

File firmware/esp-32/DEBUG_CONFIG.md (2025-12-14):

# Configuración de Debug y Logging

## Descripción

El ESP32 ahora cuenta con un sistema de logging configurable que permite controlar la cantidad de información que se envía por UART (Serial Monitor).

## Niveles de Debug

En el archivo `lib/WiFiManager/config.h` puedes configurar el nivel de debug mediante la constante `DEBUG_LEVEL`:

```cpp
#define DEBUG_LEVEL 3
```

### Niveles disponibles:

- **`0` - Sin logs (Producción)**: No se imprime nada por UART. Ideal para despliegue final.
  
- **`1` - Solo errores críticos**: Muestra únicamente errores graves que impiden el funcionamiento.
  
- **`2` - Errores y warnings**: Muestra errores y advertencias importantes.
  
- **`3` - Info importante (RECOMENDADO)**: Muestra información relevante del sistema como:
  - Inicio del ESP32
  - Conexión WiFi
  - Estado de SPIFFS
  - Cambios de modo (Physical/Web)
  - Conexiones WebSocket
  - Valores del potenciómetro cuando cambian
  
- **`4` - Debug completo**: Muestra TODOS los logs incluyendo:
  - Todos los frames UART transmitidos (con bytes en HEX)
  - Todos los mensajes WebSocket
  - Datos crudos del protocolo
  - Información detallada de cada operación

## Cómo cambiar el nivel de debug

1. Abre el archivo `lib/WiFiManager/config.h`
2. Localiza la línea: `#define DEBUG_LEVEL 3`
3. Cambia el número al nivel deseado (0-4)
4. Recompila y sube el firmware al ESP32

## Ejemplos de salida según el nivel

### DEBUG_LEVEL = 0 (Sin logs)
```
(sin salida)
```

### DEBUG_LEVEL = 3 (Recomendado - Info importante)
```
[INFO] === ESP32 Blitzcrank Firmware Starting ===
[INFO] Debug Level: 3
[INFO] Connecting to Wokwi-GUEST
[INFO] Connected to Wi-Fi
[INFO] Local IP address: http://192.168.1.100
[INFO] SPIFFS mounted successfully
[INFO] WebSocket server started on port 81
[INFO] Web server started
[INFO] Received Input Source Mode: PHYSICAL
[INFO] Physical mode - Updated potentiometer value: 45
```

### DEBUG_LEVEL = 4 (Debug completo)
```
[INFO] === ESP32 Blitzcrank Firmware Starting ===
[INFO] Debug Level: 4
[DEBUG] UART TX - STX: 0x02; TYPE: 0x03; LEN: 1; PAYLOAD: 2D
[DEBUG] Received Potentiometer: 81 -> 45
[INFO] Physical mode - Updated potentiometer value: 45
[DEBUG] Broadcasted: {"event":"potentiometerChange","value":45}
[DEBUG] [1] Received: {"type":"joystick","x":512,"y":512}
```

## Recomendaciones

- **Para desarrollo normal**: Usa `DEBUG_LEVEL 3` - te da información útil sin saturar la UART
- **Para debugging de protocolo**: Usa `DEBUG_LEVEL 4` - cuando necesites ver todos los frames y bytes
- **Para producción**: Usa `DEBUG_LEVEL 0` o `1` - minimiza el overhead y mejora el rendimiento
- **Si hay problemas de conexión**: Usa `DEBUG_LEVEL 2` o `3` - para ver warnings y errores

## Macros disponibles para desarrolladores

Si agregas nuevo código, usa estas macros para logging:

```cpp
LOG_ERROR("Mensaje de error");           // Nivel 1
LOG_WARN("Mensaje de advertencia");      // Nivel 2
LOG_INFO("Mensaje informativo");         // Nivel 3
LOG_DEBUG("Mensaje de debug");           // Nivel 4

// Con formato (estilo printf)
LOG_INFO_F("Valor: %d, Texto: %s", valor, texto);
LOG_DEBUG_F("Conectado desde %d.%d.%d.%d", ip[0], ip[1], ip[2], ip[3]);
```

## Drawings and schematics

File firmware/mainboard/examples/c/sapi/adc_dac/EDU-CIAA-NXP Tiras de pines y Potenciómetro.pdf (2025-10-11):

## EDU-CIAA-NXP Preparación de placa con Tiras de pines hembra y Potenciómetro

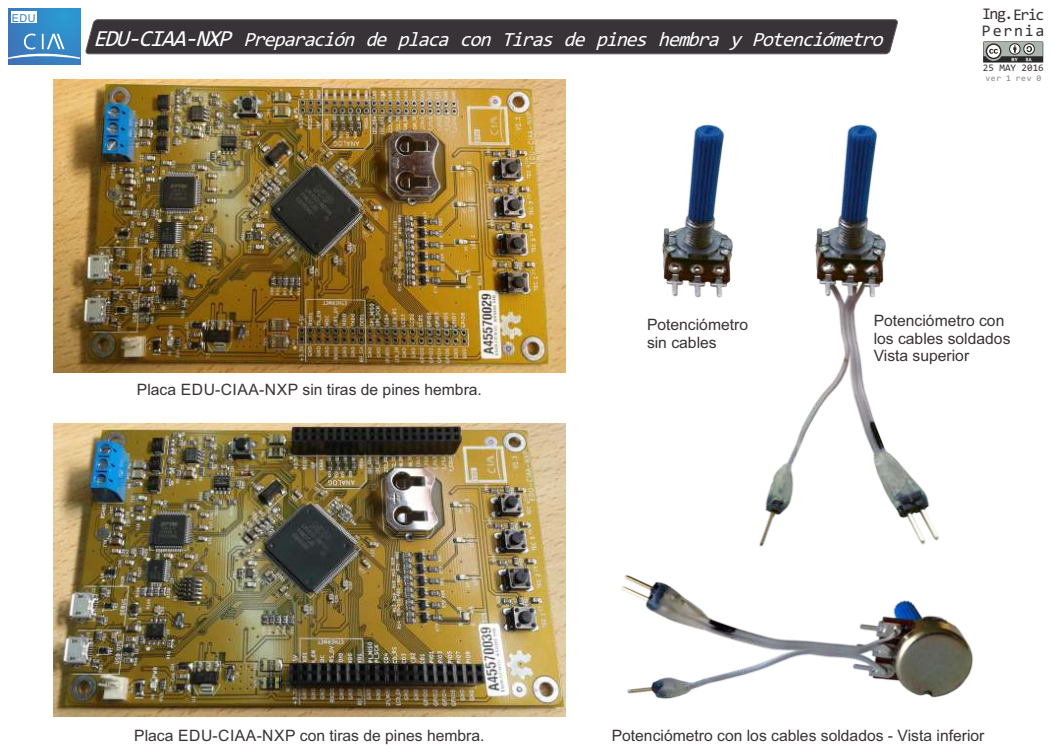
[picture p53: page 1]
EDU; Potenciómetro sin cables; 25 MAY 2016 ver 1 rev 0; Pernia; Ing.Eric

Potenciómetro con
los cables soldados
Vista superior

Placa EDU-CIAA-NXP sin tiras de pines hembra.

Placa EDU-CIAA-NXP con tiras de pines hembra.

Potenciómetro con los cables soldados - Vista inferior

## EDU-CIAA-NXP Conexión de potenciómetro

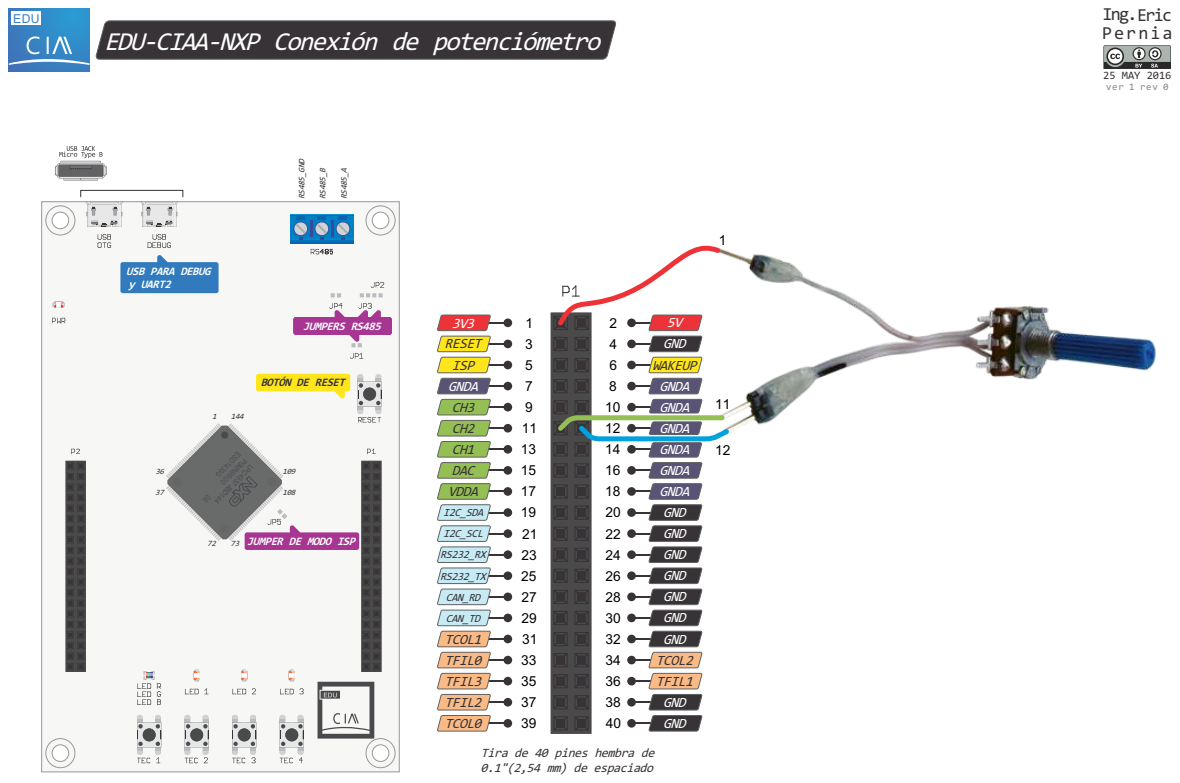
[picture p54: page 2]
EDU; 25 MAY 2016 ver 1 rev 0; Pernia; Ing.Eric; LPC4337 JBD144; ESD14330-; JUMPER DE MODO ISP; JUMPERS RS485; RS485_GND; GND; GNDA; WAKEUP; TCOL2; TFIL1; TCOL1; TFIL0; TFIL3; TFIL2; TCOL0; ISP; RESET; DAC; VDDA; I2C_SDA; I2C_SCL; CAN_RD; CAN_TD

USB PARA DEBUG
y UART2

BOTÓN DE RESET

Tira de 40 pines hembra de
0.1"(2,54 mm) de espaciado

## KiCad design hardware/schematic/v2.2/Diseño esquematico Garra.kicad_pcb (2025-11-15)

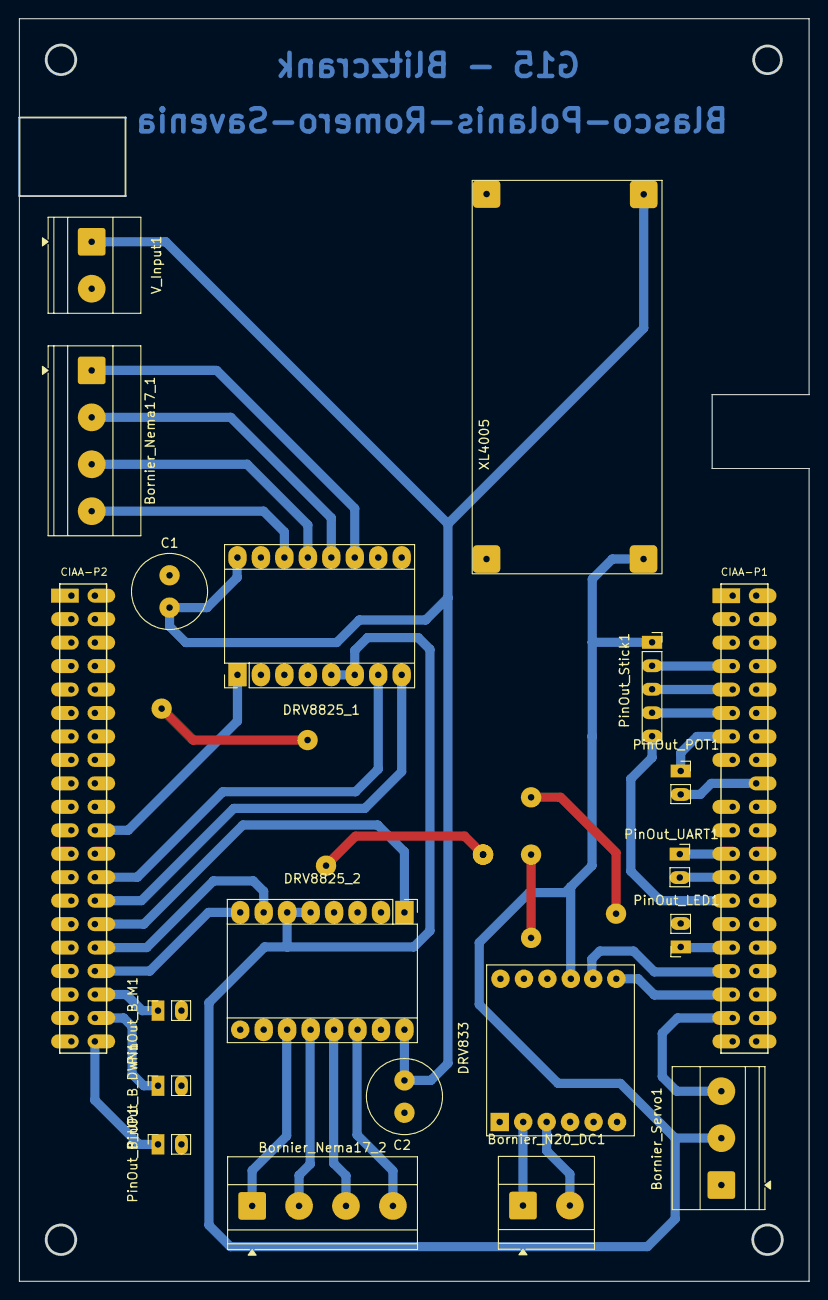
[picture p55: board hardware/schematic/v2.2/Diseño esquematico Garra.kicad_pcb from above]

Board: 2 copper layers, 85.5 x 136.7 mm, 20 parts (0 on the bottom side), 34 nets.

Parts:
Bornier_N20_DC1: Screw_Terminal_01x05; TerminalBlock_Phoenix_MKDS-1,5-2-5.08_1x02_P5.08mm_Horizont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
Bornier_Nema17_1, Bornier_Nema17_2: Screw_Terminal_01x04; TerminalBlock_Phoenix_MKDS-1,5-4-5.08_1x04_P5.08mm_Horizont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
Bornier_Servo1: Screw_Terminal_01x03; TerminalBlock_Phoenix_MKDS-1,5-3-5.08_1x03_P5.08mm_Horizont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
C1, C2: C_100uF; C_Radial_D8.0mm_H11.5mm_P3.50mm
CIAA-P1, CIAA-P2: PIN_ARRAY_20X2
DRV833: Breakout_DRV8833; Pololu_Breakout-16_15.2x20.3mm
DRV8825_1, DRV8825_2: Pololu_Breakout_DRV8825; Pololu_Breakout-16_15.2x20.3mm
PinOut_B_DWN1: Pin_Terminal_01x05; PinSocket_1x02_P2.54mm_Vertical
PinOut_B_M1: Pin_Terminal_01x05; PinSocket_1x02_P2.54mm_Vertical
PinOut_B_UP1: Pin_Terminal_01x05; PinSocket_1x02_P2.54mm_Vertical
PinOut_LED1: Pin_Terminal_01x05; PinSocket_1x02_P2.54mm_Vertical
PinOut_POT1: Pin_Terminal_01x05; PinSocket_1x02_P2.54mm_Vertical
PinOut_Stick1: Pin_Terminal_01x05; PinSocket_1x05_P2.00mm_Vertical
PinOut_UART1: Pin_Terminal_01x05; PinSocket_1x02_P2.00mm_Vertical
V_Input1: Screw_Terminal_01x02; TerminalBlock_Phoenix_MKDS-1,5-2-5.08_1x02_P5.08mm_Horizont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
XL4005: Step_Down_Power_Supply; Pololu_Breakout-16_15.2x20.3mm

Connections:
5V: Bornier_Servo1.2, DRV833.9 (VCC), DRV8825_1.5 (~RST), DRV8825_1.6 (~SLP), DRV8825_2.5 (~RST), DRV8825_2.6 (~SLP), PinOut_Stick1.1, XL4005.3 (VOUT+)
12V: C1.1, C2.1, DRV8825_1.16 (VMOT), DRV8825_2.16 (VMOT), V_Input1.1, XL4005.1 (VIN+)
A1_1: Bornier_Nema17_1.2, DRV8825_1.12 (A1)
A1_2: Bornier_Nema17_2.2, DRV8825_2.12 (A1)
A2_1: Bornier_Nema17_1.1, DRV8825_1.11 (A2)
A2_2: Bornier_Nema17_2.1, DRV8825_2.11 (A2)
B1_1: Bornier_Nema17_1.3, DRV8825_1.13 (B1)
B1_2: Bornier_Nema17_2.3, DRV8825_2.13 (B1)
B2_1: Bornier_Nema17_1.4, DRV8825_1.14 (B2)
B2_2: Bornier_Nema17_2.4, DRV8825_2.14 (B2)
B_DWN: CIAA-P2.38 (GPIO7), PinOut_B_DWN1.1
B_M: CIAA-P2.36 (GPIO5), PinOut_B_M1.1
B_UP: CIAA-P2.40 (GPIO8), PinOut_B_UP1.1
DIR1: CIAA-P2.28 (LCD2), DRV8825_1.8 (DIR)
DIR2: CIAA-P2.34 (GPIO3), DRV8825_2.8 (DIR)
EN1: CIAA-P2.22 (LCD4), DRV8825_1.1 (~EN)
EN2: CIAA-P2.30 (LCD1), DRV8825_2.1 (~EN)
GND: Bornier_Servo1.1, C1.2, C2.2, CIAA-P1.4 (GND), CIAA-P1.20 (GND), CIAA-P1.22 (GND), CIAA-P1.24 (GND), CIAA-P1.26 (GND), CIAA-P1.28 (GND), CIAA-P1.30 (GND), CIAA-P1.32 (GND), CIAA-P1.38 (GND), CIAA-P1.40 (GND), CIAA-P2.3 (GND), CIAA-P2.5 (GND), CIAA-P2.7 (GND), CIAA-P2.11 (GND), CIAA-P2.13 (GND), CIAA-P2.17 (GND), CIAA-P2.19 (GND), CIAA-P2.25 (GND), CIAA-P2.27 (GND), CIAA-P2.37 (GND), CIAA-P2.39 (GND), DRV833.10 (GND), DRV8825_1.9 (GND), DRV8825_1.15 (GND), DRV8825_2.9 (GND), DRV8825_2.15 (GND), PinOut_B_DWN1.2, PinOut_B_M1.2, PinOut_B_UP1.2, PinOut_LED1.2, V_Input1.2, XL4005.2 (VIN-), XL4005.4 (VOUT-)
GND_POT: CIAA-P1.18 (GNDA), PinOut_POT1.2
GND_Stick: CIAA-P1.7 (GNDA), PinOut_Stick1.2
IN1: CIAA-P1.35 (TFIL3), DRV833.7 (IN1)
IN2: CIAA-P1.33 (TFIL0), DRV833.8 (IN2)
LED: CIAA-P1.31 (TCOL1), PinOut_LED1.1
MOTOR_GND: Bornier_N20_DC1.2, DRV833.3 (OUT2)
MOTOR_VCC: Bornier_N20_DC1.1, DRV833.2 (OUT1)
POT: CIAA-P1.13 (CH1), PinOut_POT1.1
RS232_RX: CIAA-P1.23 (RS232_RX), PinOut_UART1.1
RS232_TX: CIAA-P1.25 (RS232_TX), PinOut_UART1.2
SERVO_PWM: Bornier_Servo1.3, CIAA-P1.37 (TFIL2)
STEP1: CIAA-P2.26 (LCD3), DRV8825_1.7 (STEP)
STEP2: CIAA-P2.32 (GPIO1), DRV8825_2.7 (STEP)
Stick_ON: CIAA-P1.27 (CAN_RD), PinOut_Stick1.5
VRX: CIAA-P1.11 (CH2), PinOut_Stick1.4
VRY: CIAA-P1.9 (CH3), PinOut_Stick1.3

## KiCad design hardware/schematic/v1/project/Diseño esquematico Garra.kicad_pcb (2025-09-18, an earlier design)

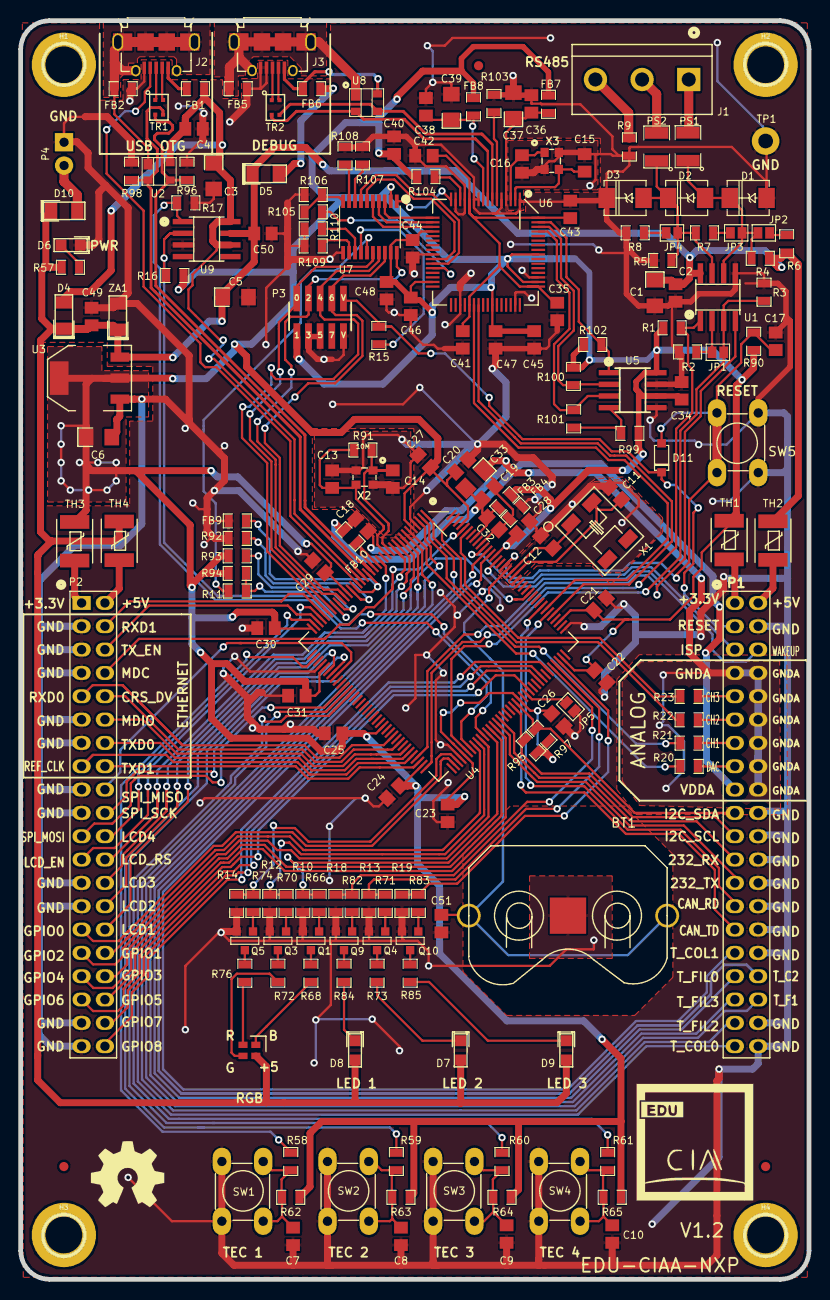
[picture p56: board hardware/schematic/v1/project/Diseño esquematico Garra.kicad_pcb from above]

Board: 2 copper layers, 85.8 x 137.0 mm, 195 parts (0 on the bottom side), 166 nets.

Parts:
BT1: BK-913; BK-913-ND
C1: 10uF; c_1206_tantalio
C2, C4, C7, C8, C9, C10, C17, C18, C19, C20, C21, C22, C23, C24, C25, C26, C27, C28, C29, C30, C31, C32, C34, C36, C38, C40, C41, C42, C43, C44, C45, C46, C47, C48, C49, C50, C51: 100nF; c_0805
C3, C5, C6, C33, C37, C39: 10uF; c_1206_tantalio_1
C11, C12, C13, C14, C15, C16: 20p; c_0805
C35: 3.3uF; c_0805
D1, D2, D3: PSD12C; DO-214AA(SMB)
D4, D5, D10: PMEG3020EH; SOD123F
D6: LED red; LED-0805
D7, D8, D9: LED; LED-0805
D11: LL4148; SOD-123
F1, F2, F3: fiducial; Fiducial_1mm_TOP
F4, F5, F6: fiducial; Fiducial_1mm_BOT
FB1, FB5, FB6, FB9, FB10: MI0805M221R-10; SM0805
FB2, FB3, FB4, FB7, FB8: HZ0805E601R-10; SM0805
G101: OSHWA
H1, H2, H3, H4: 4mm; 1pin
J1: TB_1X3; bornier3
J2, J3: ZX62D-AB-5P8; USB_microAB_ZX62-AB-5P8
JP1, JP2, JP3, JP4: JUMPER-2; GS2
JP5: ISP; GS2
LED1: LED_ARBG; PLCC-4
P1, P2: CONN_20X2; PIN_ARRAY_20X2
P3: Cortex-Debug; Pin_Array_5x2_1.27mm_SMD
P4: 5Vcc Input; Con_2P
PS1, PS2: USMF020; SM1210
Q1, Q3, Q4, Q5, Q9, Q10: 2N7002; SOT23GDS
R1, R2, R3: 4K7; SM0805
R4, R5, R90: 100K; SM0805
R6, R8: 390; SM0805
R7: 200; SM0805
R9: 100; SM0805
R10, R12, R13, R14, R18, R19: 330k; SM0805
R11, R15, R107, R108, R109, R110: 0; SM0805
R16, R17, R62, R63, R64, R65, R66, R70, R71, R74, R82, R83, R106: 10k; SM0805
R20: 470; SM0805
R21, R22, R23: 1k2; SM0805
R57, R58, R59, R60, R61, R104: 1k; SM0805
R68, R72, R73, R76, R84, R85: 680; SM0805
R91: 10M; SM0805
R92: 12K; SM0805
R93, R94, R99, R100, R102: 10K; SM0805
R95, R97: 2.2k; SM0805
R96, R98: 15K; SM0805
R101: 2.2K; SM0805
R103: 12K 1%; SM0805
R105: 270; SM0805
SW1: TEC_1; PUSH_SWITCH_THT
SW2: TEC_2; PUSH_SWITCH_THT
SW3: TEC_3; PUSH_SWITCH_THT
SW4: TEC_4; PUSH_SWITCH_THT
SW5: RESET; PUSH_SWITCH_THT
TH1, TH2, TH3, TH4: MF-MSMF030-2; MF-MSMF
TP1: 4mm; GNDpin
TR1, TR2: DLW21HN900SQ2; SRF2012
U1: SN65HVD1176DR; -SOIC8
U2, U8: PRTR5V0U2X; sot143B
U3: NCP1117ST33T3G; SOT223
U4: LPC4337JBD144; LQFP144-M05
U5: 93C46; -SOIC8
U6: FT2232H; LQFP64-M05
U7: TXB0108; tssop-20
U9: MIC2025; -SOIC8
X1: 32.768K; 4SOJ
X2, X3: 12MHz; FA238V-XTAL
ZA1: SMAZ5V6; SOD123F

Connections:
+3.3V: C6.1, C20.2, C21.2, C22.2, C23.2, C24.2, C25.2, C26.2, C27.2, C28.2, C29.2, C30.2, C31.2, C34.1, C40.2, C44.1, C45.1, C46.1, C47.1, C48.2, FB3.1, FB7.2, FB8.2, P3.1, R1.1, R16.2, R62.1, R63.1, R64.1, R65.1, R90.2, R93.2, R94.2, R95.1, R97.1, R99.1, R100.1, R102.1, R104.1, TH1.2, TH3.2, U3.2, U3.4, U4.5, U4.25, U4.36, U4.41, U4.59, U4.71, U4.77, U4.94, U4.107, U4.111, U4.131, U4.141, U5.6, U5.8, U6.20, U6.31, U6.42, U6.50, U6.56, U7.2, U7.19
+3.3VADC: C18.1, C19.1, C32.1, C33.2, FB3.2, FB10.2, P1.17, U4.137
+5V: C1.2, C2.1, C5.1, C49.1, C50.1, D4.2, D5.2, D7.1, D8.1, D9.1, D10.2, LED1.4, R4.1, R6.1, R57.1, TH2.2, TH4.2, U1.8, U3.3, U9.7, ZA1.2
/CPU/ADC0_1: R21.1, U4.2
/CPU/ADC0_2: R22.1, U4.143
/CPU/ADC0_3: R23.1, U4.139
/CPU/CAN_RD: P1.27, U4.114
/CPU/CAN_TD: P1.29, U4.116
/CPU/CHJ3: FB5.1, J3.7, J3.8, J3.9, U8.1
/CPU/DAC: R20.1, U4.6
/CPU/EECLK: R100.2, U5.2, U6.62
/CPU/EECS: R102.2, U5.1, U6.63
/CPU/EEDATA: R101.1, U5.3, U6.61
/CPU/ENET_CRS_DV: P2.10, U4.64
/CPU/ENET_MDC: P2.8, U4.140
/CPU/ENET_MDIO: P2.12, U4.66
/CPU/ENET_REF_CLK: P2.15, U4.68
/CPU/ENET_RXD0: P2.9, U4.62
/CPU/ENET_RXD1: P2.4, U4.32
/CPU/ENET_TXD0: P2.14, U4.67
/CPU/ENET_TXD1: P2.16, U4.70
/CPU/ENET_TX_EN: P2.6, U4.34
/CPU/FT_OE: R105.2, U6.28
/CPU/FT_RST: U6.27, U7.7
/CPU/FT_TCK: U6.16, U7.1
/CPU/FT_TDI: U6.17, U7.3
/CPU/FT_TDO: U6.18, U7.4
/CPU/FT_TMS: U6.19, U7.5
/CPU/FT_TRST: U6.26, U7.6
/CPU/FT_XTIN: C15.2, U6.2, X3.3
/CPU/FT_XTOUT: C16.2, U6.3, X3.1
/CPU/GPIO0: P2.29, U4.74
/CPU/GPIO1: P2.32, U4.80
/CPU/GPIO2: P2.31, U4.82
/CPU/GPIO3: P2.34, U4.85
/CPU/GPIO4: P2.33, U4.86
/CPU/GPIO5: P2.36, U4.97
/CPU/GPIO6: P2.35, U4.100
/CPU/GPIO7: P2.38, U4.101
/CPU/GPIO8: P2.40, U4.103
/CPU/I2C_SCL: P1.21, R95.2, U4.92
/CPU/I2C_SDA: P1.19, R97.2, U4.93
/CPU/ISP: P1.5, U4.134
/CPU/LCD1: P2.30, U4.9
/CPU/LCD2: P2.28, U4.10
/CPU/LCD3: P2.26, U4.11
/CPU/LCD4: P2.22, U4.35
/CPU/LCD_RS: P2.24, U4.15
/CPU/LED0_B: R10.1, R66.1, U4.84
/CPU/LED0_G: R12.1, R70.1, U4.81
/CPU/LED0_R: R14.1, R74.1, U4.75
/CPU/LED1: R18.1, R82.1, U4.104
/CPU/LED2: R13.1, R71.1, U4.105
/CPU/LED3: R19.1, R83.1, U4.106
/CPU/PULS_0: R58.1, U4.38
/CPU/PULS_1: R59.1, U4.42
/CPU/PULS_2: R60.1, U4.43
/CPU/PULS_3: R61.1, U4.49
/CPU/RESET: D11.2, P1.3, P3.10, R15.1
/CPU/RS232_RXD: P1.23, U4.88
/CPU/RS232_TXD: P1.25, U4.87
/CPU/RS485_DIR: JP1.1, R3.1, U1.3, U4.78
/CPU/RS485_RXD: R1.2, U1.1, U4.72
/CPU/RS485_TXD: U1.4, U4.69
/CPU/RST: R15.2, U7.14
/CPU/RTCX1: C11.2, U4.125, X1.4
/CPU/RTCX2: C12.2, U4.126, X1.1
/CPU/SPI_MISO: P2.18, U4.44
/CPU/SPI_MOSI: P2.21, U4.47
/CPU/SPI_SCK: P2.20, U4.120
/CPU/TCK: P3.4, U4.27, U7.20
/CPU/TDI: P3.8, U4.26, U7.18
/CPU/TDO: P3.6, U4.31, U7.17
/CPU/TEC_COL0: P1.39, U4.48
/CPU/TEC_COL1: P1.31, U4.132
/CPU/TEC_COL2: P1.34, U4.133
/CPU/TEC_F0: P1.33, U4.1
/CPU/TEC_F1: P1.36, U4.3
/CPU/TEC_F2: P1.37, U4.8
/CPU/TEC_F3: P1.35, U4.7
/CPU/TMS: P3.2, U4.30, U7.16
/CPU/TRST: R11.2, U7.15
/CPU/U2_RXD: U4.115, U6.38
/CPU/U2_TXD: U4.113, U6.39
/CPU/USB_DEBUG_VBUS: D5.1, FB6.2
/CPU/USB_DM: R98.1, TR1.3, U2.2, U4.20
/CPU/USB_DP: R96.1, TR1.2, U2.3, U4.18
/CPU/USB_ID: J2.4, U4.22
/CPU/USB_JTAG_1.8V: C35.1, C41.1, C42.1, C43.1, U6.12, U6.37, U6.49, U6.64
/CPU/USB_JTAG_DM: TR2.3, U6.7, U8.3
/CPU/USB_JTAG_DP: TR2.2, U6.8, U8.2
/CPU/USB_PPWR: R17.2, U4.79, U9.1
/CPU/USB_PWR_FAULT: R16.1, U4.83, U9.2
/CPU/USB_VBUS: C3.1, C4.1, D4.1, FB1.2, U2.4, U4.21, U9.6, U9.8
/CPU/XTAL1: C14.2, R91.1, U4.12, X2.1
/CPU/XTAL2: C13.2, R91.2, U4.13, X2.3
/CPU/nTRST: R11.1, R94.1, U4.29
/GPIO/LCD_EN: P2.23, U4.33
/GPIO/WAKEUP: P1.6, U4.130
/USB_OTG/CHJ2: FB2.2, J2.7, J2.8, J2.9, U2.1
GND: BT1.2, C1.1, C2.2, C3.2, C4.2, C5.2, C6.2, C7.2, C8.2, C9.2, C10.2, C11.1, C12.1, C13.1, C14.1, C15.1, C16.1, C17.2, C20.1, C21.1, C22.1, C23.1, C24.1, C25.1, C26.1, C27.1, C28.1, C29.1, C30.1, C31.1, C34.2, C35.2, C36.2, C37.2, C38.2, C39.2, C40.1, C41.2, C42.2, C43.2, C44.2, C45.2, C46.2, C47.2, C48.1, C49.2, C50.2, C51.2, D1.1, D3.2, D6.2, FB2.1, FB4.1, FB5.2, FB9.1, J2.5, J3.4, J3.5, JP5.1, P1.4, P1.20, P1.22, P1.24, P1.26, P1.28, P1.30, P1.32, P1.38, P1.40, P2.3, P2.5, P2.7, P2.11, P2.13, P2.17, P2.19, P2.25, P2.27, P2.37, P2.39, P3.3, P3.5, P3.9, P4.1, Q1.S, Q3.S, Q4.S, Q5.S, Q9.S, Q10.S, R2.2, R3.2, R5.2, R8.2, R9.1, R10.2, R12.2, R13.2, R14.2, R17.1, R18.2, R19.2, R92.2, R96.2, R98.2, R103.1, R106.2, R107.1, R108.1, R109.1, R110.1, SW1.3, SW1.4, SW2.3, SW2.4, SW3.3, SW3.4, SW4.3, SW4.4, SW5.3, SW5.4, TP1.1, U1.5, U3.1, U4.4, U4.40, U4.76, U4.109, U5.5, U5.7, U6.1, U6.5, U6.10, U6.11, U6.13, U6.15, U6.25, U6.35, U6.47, U6.51, U7.11, U9.3, X2.2, X2.4, X3.2, X3.4, ZA1.1
GNDA: C18.2, C19.2, C32.2, C33.1, FB4.2, P1.7, P1.8, P1.10, P1.12, P1.14, P1.16, P1.18, U4.135
unnamed: JP5.2, U4.96
unnamed: J3.3, TR2.1
unnamed: J3.2, TR2.4
unnamed: C38.1, C39.1, FB8.1, U6.9
unnamed: R103.2, U6.6
unnamed: R104.2, U6.14
unnamed: R99.2, R101.2, U5.4
unnamed: R107.2, U7.8
unnamed: C36.1, C37.1, FB7.1, U6.4
unnamed: R110.2, U7.13
unnamed: R109.2, U7.12
unnamed: R105.1, R106.1, U7.10
unnamed: R108.2, U7.9
unnamed: FB9.2, U4.19, U4.23
unnamed: BT1.1, C51.1, U4.127
unnamed: FB10.1, U4.16, U4.17
unnamed: FB6.1, J3.1, U8.4
unnamed: R92.1, U4.24
unnamed: R93.1, U4.28
unnamed: C17.1, D11.1, R90.1, SW5.1, SW5.2, U4.128
unnamed: J1.3, R9.2
unnamed: JP4.1, R8.1
unnamed: JP3.1, R7.1
unnamed: J1.2, PS2.2
unnamed: J1.1, PS1.2
unnamed: JP2.2, R6.2
unnamed: JP1.2, R2.1, U1.2
unnamed: D1.2, D2.1, JP2.1, JP3.2, PS1.1, R4.2, U1.6
unnamed: D2.2, D3.1, JP4.2, PS2.1, R5.1, R7.2, U1.7
unnamed: D10.1, P4.2
unnamed: D6.1, R57.2
unnamed: FB1.1, J2.1
unnamed: J2.2, TR1.4
unnamed: J2.3, TR1.1
unnamed: P1.1, TH1.1
unnamed: P1.2, TH2.1
unnamed: P1.15, R20.2
unnamed: P1.13, R21.2
unnamed: P1.11, R22.2
unnamed: P1.9, R23.2
unnamed: P2.2, TH4.1
unnamed: P2.1, TH3.1
unnamed: LED1.3, R72.1
unnamed: D7.2, R73.1
unnamed: Q4.G, R71.2
unnamed: Q4.D, R73.2
unnamed: Q5.G, R74.2
unnamed: LED1.2, R76.1
unnamed: Q3.G, R70.2
unnamed: Q3.D, R72.2
unnamed: Q5.D, R76.2
unnamed: Q10.G, R83.2
unnamed: Q10.D, R85.2
unnamed: D9.2, R85.1
unnamed: D8.2, R84.1
unnamed: C8.1, R59.2, R63.2, SW2.1, SW2.2
unnamed: C7.1, R58.2, R62.2, SW1.1, SW1.2
unnamed: Q9.G, R82.2
unnamed: Q9.D, R84.2
unnamed: Q1.G, R66.2
unnamed: LED1.1, R68.1
unnamed: Q1.D, R68.2
unnamed: C9.1, R60.2, R64.2, SW3.1, SW3.2
unnamed: C10.1, R61.2, R65.2, SW4.1, SW4.2

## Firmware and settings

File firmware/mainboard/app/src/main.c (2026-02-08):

#include "FreeRTOS.h"
#include "task.h"
#include "sapi.h"
#include "tasks.h"
#include "handlers.h"
#include "event_system.h"
#include "priority.h"
#include "heap.h"
#include "debug.h"
#include "controls_state.h"

#define UART_USB_BAUD_RATE 115200U
TaskHandle_t xControlXYAxisTaskHandle = NULL;
TaskHandle_t xControlGripperTaskHandle = NULL;
TaskHandle_t xControlZAxisTaskHandle = NULL;
TaskHandle_t xSwitchModeTaskHandle = NULL; 
TaskHandle_t xServoTaskHandle = NULL;
TaskHandle_t xXYStepperTaskHandle = NULL;
TaskHandle_t xZMotorTaskHandle = NULL;
TaskHandle_t xConnectionTaskHandle = NULL;

ControlsState_t globalState;

int main(void) {
    boardConfig();
    uartConfig(UART_USB, UART_USB_BAUD_RATE);
    adcConfig(ADC_ENABLE);
    ControlsState_Init();
    LOG_PRINTLN("=== System Starting ===");
    LOG_PRINTLN("Generating tasks...");
    xTaskCreate(controlGripperTask, "GRIPPER", HEAP_GRIPPER_SIZE, NULL, PRIORITY_CONTROL_GRIPPER, &xControlGripperTaskHandle);
    xTaskCreate(controlXYAxisTask, "XY_AXIS", HEAP_XY_AXIS_SIZE, NULL, PRIORITY_CONTROL_XY_AXIS, &xControlXYAxisTaskHandle);
    xTaskCreate(controlZAxisTask, "Z_AXIS", HEAP_Z_AXIS_SIZE, NULL, PRIORITY_CONTROL_Z_AXIS, &xControlZAxisTaskHandle);
    xTaskCreate(servoTask, "SERVO", HEAP_GRIPPER_SIZE, NULL, PRIORITY_CONTROL_GRIPPER, &xServoTaskHandle);
    xTaskCreate(switchModeTask, "SWITCH", HEAP_SWITCH_MODE_SIZE, NULL, PRIORITY_SWITCH_MODE, &xSwitchModeTaskHandle);
    xTaskCreate(XYStepperTask, "STEPPER", HEAP_XYSTEPPER_SIZE, NULL, PRIORITY_XY_STEPPER, &xXYStepperTaskHandle);
    xTaskCreate(ZMotorTask, "Z_MOTOR", HEAP_Z_MOTOR_SIZE, NULL, PRIORITY_Z_MOTOR, &xZMotorTaskHandle);
    xTaskCreate(controlConnectionTask, "CONNECTION", HEAP_CONNECTION_SIZE, NULL, PRIORITY_CONNECTION_TASK, NULL);

    UART_TaskCreate();

    LOG_PRINTLN("Initializing event system...");
    initEventSystem();
    LOG_PRINTLN("Starting scheduler...");
    vTaskStartScheduler();
    while (TRUE) {
        LOG_PRINTLN("Error: there is not enough memory to start the scheduler.");
    }
    return 0;
}

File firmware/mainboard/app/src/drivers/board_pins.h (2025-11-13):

#ifndef _BOARD_PINS_H_
#define _BOARD_PINS_H_

#include "sapi.h"   // Incluye tipos y macros base

//---------------------------------------------------------
// UART
//---------------------------------------------------------
#define UART_DEBUG        UART_USB



//---------------------------------------------------------
// ADC (potenciometer)
//---------------------------------------------------------
#define POTENCIOMETER_PIN     CH1



//---------------------------------------------------------
// SERVO (using potenciometer value)
//---------------------------------------------------------
#define SERVO_PIN      SERVO2   // T_FIL2 de la EDU-CIAA

//---------------------------------------------------------
// DC Motor
//---------------------------------------------------------
#define DC_MOTOR_GND_PIN T_FIL0
#define DC_MOTOR_VCC_PIN T_FIL3

//---------------------------------------------------------
// BUTTONS
//---------------------------------------------------------
#define BUTTON_UP_PIN    GPIO5
#define BUTTON_DOWN_PIN  GPIO7
#define BUTTON_SWITCH_PIN GPIO8

//---------------------------------------------------------
// LED
//---------------------------------------------------------
#define LED_SWITCH_PIN T_COL1


//---------------------------------------------------------
// JOYSTICK
//---------------------------------------------------------
#define JOYSTICK_X_PIN        CH3
#define JOYSTICK_Y_PIN        CH2

//---------------------------------------------------------
// STATE
//---------------------------------------------------------
#define CONTROLLER_CONNECTION_PIN   CAN_RD

//---------------------------------------------------------
// STEPPER MOTOR 
//---------------------------------------------------------
#define STEPPER_MOTOR_STEP1_PIN   LCD3
#define STEPPER_MOTOR_DIR1_PIN    LCD2
#define STEPPER_MOTOR_ENABLE1_PIN  LCD4
#define STEPPER_MOTOR_STEP2_PIN   GPIO1
#define STEPPER_MOTOR_DIR2_PIN    GPIO3
#define STEPPER_MOTOR_ENABLE2_PIN  LCD1



#endif /* _BOARD_PINS_H_ */

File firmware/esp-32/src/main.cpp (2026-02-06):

#include <Arduino.h>
#include <WebServer.h>
#include "wifi_connectivity.h"
#include "spiffs_manager.h"
#include "routes.h"
#include "uart_manager.h"
#include "websocket_manager.h"
#include "wifi_config.h"
#include "debug_config.h"

WebServer server(80);
WebSocketManager wsManager(81);
UARTManager uartManager; // UART2 por defecto
Frame_t frame;

unsigned long lastWatchdogFeed = 0;
const unsigned long WATCHDOG_TIMEOUT = 30000; // 30 segundos

void setup() {
  Serial.begin(115200);
  delay(500); // Dar tiempo al serial para inicializar
  
  LOG_INFO("=== ESP32 Blitzcrank Firmware Starting ===");
  LOG_INFO_F("Debug Level: %d", DEBUG_LEVEL);
  
  uartManager.begin();

  setupWiFi();
  if (!initSPIFFS()) {
    LOG_ERROR("Fatal: SPIFFS init failed");
    return;
  }
  
  setupRoutes(server, uartManager);
  server.begin();

  // Inicializar WebSocket
  wsManager.setUARTManager(&uartManager);
  wsManager.begin();

  LOG_INFO("Web server started");
  lastWatchdogFeed = millis();
}

void loop() {
  server.handleClient();
  wsManager.handle();
  uartManager.handleIncomingData();
  uartManager.processPendingSends();
  
  // Feed al watchdog cada 30 segundos para evitar resets
  if (millis() - lastWatchdogFeed > WATCHDOG_TIMEOUT) {
    lastWatchdogFeed = millis();
  }
  
  // Pequeño delay para evitar saturar el watchdog
  delay(10);
}

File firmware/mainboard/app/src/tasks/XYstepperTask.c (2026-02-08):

#include "FreeRTOS.h"
#include "queue.h"
#include "task.h"
#include "sapi.h"
#include "board_pins.h"
#include "button.h"
#include "event_system.h"
#include <stdlib.h>
#include "utils.h"
#include "debug.h"
#include "sapi_cyclesCounter.h"
#include "joystick_constants.h"
#include "task_constants.h"

#define STEPPER_DEAD_ZONE 150U
#define STEPPER_MAX_SPEED_DELAY_US 2000U

static void enableDWT(void) {
    CoreDebug->DEMCR |= CoreDebug_DEMCR_TRCENA_Msk;
    DWT->CYCCNT = 0;
    DWT->CTRL |= DWT_CTRL_CYCCNTENA_Msk;
}

void XYStepperTask(void *pvParameters) {
    JoystickEvent_t command = { .x = JOYSTICK_CENTER_VALUE, .y = JOYSTICK_CENTER_VALUE };
    boardConfig();
    enableDWT();
    cyclesCounterInit(SystemCoreClock);

    gpioConfig(STEPPER_MOTOR_STEP1_PIN, GPIO_OUTPUT);
    gpioConfig(STEPPER_MOTOR_DIR1_PIN, GPIO_OUTPUT);
    gpioConfig(STEPPER_MOTOR_ENABLE1_PIN, GPIO_OUTPUT);
    gpioWrite(STEPPER_MOTOR_ENABLE1_PIN, ON);

    gpioConfig(STEPPER_MOTOR_STEP2_PIN, GPIO_OUTPUT);
    gpioConfig(STEPPER_MOTOR_DIR2_PIN, GPIO_OUTPUT);
    gpioConfig(STEPPER_MOTOR_ENABLE2_PIN, GPIO_OUTPUT);
    gpioWrite(STEPPER_MOTOR_ENABLE2_PIN, ON);

    LOG_PRINTLN("[Stepper Task] Iniciada correctamente (XY gantry)");

    uint32_t lastStepA = 0, lastStepB = 0;
    bool enabled = false;

    const uint32_t delayCycles = STEPPER_MAX_SPEED_DELAY_US * (SystemCoreClock / 1000000U);

    for (;;) {
        JoystickEvent_t newCommand;
        if (xTaskNotifyWait(0, 0, (uint32_t *)&newCommand, pdMS_TO_TICKS(STEPPER_NOTIFY_WAIT_MS)) == pdTRUE)
            command = newCommand;

        int16_t joyX = command.x - JOYSTICK_CENTER_VALUE;
        int16_t joyY = command.y - JOYSTICK_CENTER_VALUE;

        if (abs(joyX) < STEPPER_DEAD_ZONE && abs(joyY) < STEPPER_DEAD_ZONE) {
            if (enabled) {
                gpioWrite(STEPPER_MOTOR_ENABLE1_PIN, ON);
                gpioWrite(STEPPER_MOTOR_ENABLE2_PIN, ON);
                enabled = false;
            }
            vTaskDelay(pdMS_TO_TICKS(STEPPER_IDLE_DELAY_MS));
            continue;
        } else if (!enabled) {
            gpioWrite(STEPPER_MOTOR_ENABLE1_PIN, OFF);
            gpioWrite(STEPPER_MOTOR_ENABLE2_PIN, OFF);
            enabled = true;
        }

        int16_t speedA = joyX + joyY;
        int16_t speedB = -joyX + joyY;

        bool moveA = (abs(speedA) >= STEPPER_DEAD_ZONE);
        bool moveB = (abs(speedB) >= STEPPER_DEAD_ZONE);

        gpioWrite(STEPPER_MOTOR_DIR1_PIN, (speedA > 0) ? ON : OFF);
        gpioWrite(STEPPER_MOTOR_DIR2_PIN, (speedB > 0) ? ON : OFF);

        uint32_t now = DWT->CYCCNT;

        if (moveA && (now - lastStepA) >= delayCycles) {
            gpioWrite(STEPPER_MOTOR_STEP1_PIN, !gpioRead(STEPPER_MOTOR_STEP1_PIN));
            lastStepA = now;
        }

        if (moveB && (now - lastStepB) >= delayCycles) {
            gpioWrite(STEPPER_MOTOR_STEP2_PIN, !gpioRead(STEPPER_MOTOR_STEP2_PIN));
            lastStepB = now;
        }

        vTaskDelay(pdMS_TO_TICKS(STEPPER_LOOP_DELAY_MS));
    }
}

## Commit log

2025-09-18 EDU-CIAA Schematics/PCB Kicad
    [EDU_CIAA_Pinout_Rev_1.0.ods, Modulos_hardwar_a_incluir.ods, ON_BOARD_IO-2025-09-18-11-02-53.sch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]
2025-09-22 New Kicad scheme
    [Diseño esquematico Garra.kicad_pcb, Diseño esquematico Garra.kicad_sch]
2025-09-25 style: add project structure
    [EDU_CIAA_Pinout_Rev_1.0.ods, Modulos_hardwar_a_incluir.ods, ON_BOARD_IO-2025-09-18-11-02-53.sch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]
2025-09-25 style: Refactor code structure for improved readability and maintainability
    [Diseño esquematico Garra.kicad_pcb, Diseño esquematico Garra.kicad_sch]
2025-09-25 ESP32 Schematic implemented
    [Diseño esquematico Garra.kicad_sch, Esp32 (page2).kicad_sch]
2025-09-25 Fixes to Schematic
    [Diseño esquematico Garra.kicad_sch, Esp32 (page2).kicad_sch]
2025-09-29 Schematics updated + PCB
    [Diseño esquematico Garra.kicad_pcb, Diseño esquematico Garra.kicad_sch]
2025-09-29 Schematics pdf + EDU-NXP folder deleted
    [Diseño esquematico Garra.kicad_sch]
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2025-09-29 schematic update
    [Diseño esquematico Garra.kicad_sch]
2025-09-30 Added buttons/potentimeter to schematics
    [Diseño esquematico Garra.kicad_sch]
2025-09-30 Diseño 3d de la garra, falta el bajado y la garra en si
    [Diseño-Garra-3D.stl]
2025-10-01 feat: replace driver DDRV8833 for BTS7960
2025-10-01 Schematics updated - pins, PowerSupply
    [Diseño esquematico Garra.kicad_sch, Diseño-Garra-3D.stl]
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2025-10-01 Schematics updated - borniers,pins
    [Diseño esquematico Garra.kicad_sch]
2025-10-01 Schematics fixed
    [Diseño esquematico Garra.kicad_sch]
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2025-10-02 Schematics updated - Step down PS & capacitor
    [Diseño esquematico Garra.kicad_sch]
2025-10-02 Schematic pdf name fix
2025-10-05 Added all stl files for 3d printing
    [Bottom_XY_clamshell_V2.stl, Top_XY_clamshell_V4.stl, X_support_L.stl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]
2025-10-05 style: enhance directory naming
    [Bottom_XY_clamshell_V2.stl, Diseño esquematico Garra.kicad_pcb, Diseño esquematico Garra.kicad_sch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]
2025-10-07 Schematics updated
    [Diseño esquematico Garra.kicad_sch]
2025-10-08 Added footprints to Schematic
    [Diseño esquematico Garra.kicad_sch]
2025-10-09 PCB started
    [Diseño esquematico Garra.kicad_pcb, Diseño esquematico Garra.kicad_sch, Esquematico_Base_v2.kicad_sch]
2025-10-09 PCB progress
    [Diseño esquematico Garra.kicad_pcb, Diseño esquematico Garra.kicad_sch]
2025-10-10 Added required stls for pulley design
    [Bottom_XY_clamshell_V2.stl, Polea.stl, Soporte Gancha v2.stl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]
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2025-10-11 feat: add firmwarev3
    [lpc4337.cfg, lpc4337_new.cfg, lpc4337_old.cfg]
2025-10-13 feat: Implemented a new main.c file with two LED tasks that toggle LED1 and LED2 at different intervals with a RTOS approach
2025-10-13 Official EDU-CIAA footprints added
    [Diseño esquematico Garra.kicad_pcb]
2025-10-13 PCB Updated
    [Diseño esquematico Garra.kicad_pcb, Diseño esquematico Garra.kicad_sch]
2025-10-14 Esp32 webpage (#1)
    * feat: Add Wi-Fi connectivity and web server functionality with HTML control interface to esp32
    * feat: Refactor Wi-Fi connectivity and web server implementation with new HTML/CSS interface
    * feat: Implement hold functionality for button actions in script.js
    * feat: Refactor Wi-Fi connectivity and SPIFFS management with new routing structure
    * feat: Update project structure in README.md for improved clarity and organization
2025-10-15 Add initial FreeRTOS configuration and example tasks for LED control
    - Created launch configuration for PlatformIO debugging in esp-32 firmware.
    - Added config.mk for build options and library usage in mainboard application.
    - Included FreeRTOSConfig.h with standard configurations for FreeRTOS.
    - Defined main.h with basic structure for the main application.
    - Implemented main.c with two tasks to toggle LEDs at different intervals.
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2025-10-16 feat: implement servo control with PWM mapping and add initial task files
2025-10-17 feat(uart): add UART communication with EDU-CIAA feat(web): enhance web accessibility and control feedback (#2)
    * feat: Add mode switch for web control and update control states in UI
    * feat: add how joystick 2-axis works
    * feat: enhance UI with control title styl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
2025-10-17 Esp32 (#3)
    * feat: enhance UI with control title styling and prevent text selection
    * feat: add favicon and enhance hold indicator styles with animations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
2025-10-18 feat: implement control tasks for gripper, XY, and Z axes with event system integration
2025-10-18 feat: add task handles for control tasks and enhance switch mode task functionality
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2025-10-21 Esp32 (#5)
    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
    [controlZAxisTask.c]
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2025-10-22 added controller 3d designs for printing
    [Controller-Top-V2.stl, Controller-bottom-V2.stl]
2025-10-23 feat: Diseño 3D de control completado
    [Controller-Top-V2.stl, Controller-bottom-V2.stl]
2025-10-24 feat: add PCB layout (#7)
    * refactor
    * feat: PCB routing first stage completed
    * docs: Schematics PDF added
    * fix: PCB border colision
    * feat: Copper layers added to the PCB
    * feat: New PCB design with new components [LED, B_M]
    * feat: add through holes for connectivity & GNDs links
    * feat: hole diameter adjustment
    * fix: PDF
    ---------
    [Diseño esquematico Garra.kicad_pcb, Diseño esquematico Garra.kicad_sch]
2025-10-25 feat: Made Corrections to claw mechanism to improve the performance of the gears
    [Soporte Garra v3.stl, gear_left_v2.stl, gear_right_v2.stl]
2025-10-26 feat: increased hole sizes for claw pieces to reduce friction
    [Soporte Garra v3.stl, arm_left.stl, arm_left_v2.stl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]
2025-10-27 feat: improved fitting of the gears. Modified controller bottom to include holes for perfboard
    [Controller-bottom-v3.stl]
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2025-10-28 Pcb branch (#8)
    * feat: change route system in PCB
    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
    [Diseño esquematico Garra.kicad_sch]
2025-10-31 docs: reallocated files improperly placed
    [Soporte Garra v3.stl, gear_left_v2.stl, gear_right_v2.stl]
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2025-11-03 fix: swap GPIO pins for button and joystick functionality
    [board_pins.h]
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2025-11-03 Pcb branch (#11)
    * feat: add new esp32 schematic
    * feat: complete PCB
    * feat: take png and pdf from finished schematic
    * feat: valid pdf PCB template
    * fix: Expand PCB routes and copper holes
    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
    [Diseño esquematico Garra.kicad_pcb, Diseño esquematico Garra.kicad_sch, ESP32.kicad_sch]
2025-11-11 feat: Update PCB structure
    * feat: Change PCB design and clearance
    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
    [Diseño esquematico Garra.kicad_pcb, Diseño esquematico Garra.kicad_sch, ESP32.kicad_sch]
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2025-11-14 feat: fix controller not working when it was plugged in
    [main.c]
2025-11-15 Pcb branch (#14)
    * feat: Change Stick_on from ISP to CAN_RD
    Co-au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
    [Diseño esquematico Garra.kicad_pcb, Diseño esquematico Garra.kicad_sch]
2025-11-17 feat: increase hole diameter for PinOuts
    [Diseño esquematico Garra.kicad_pcb]
2025-12-01 Esp32 (#15)
    * feat: add favicon and enhance hold indicator styles with animation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
    [main.c]
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2025-12-06 Revert "Esp32 (#15)" (#17)
    This reverts commit bf51cb744312f9b626049e7e4bf70f72b9cf64da.
    [main.c]
2025-12-14 Mainboard (#18)
    * feat: add debug prints for UART frame validation and connection state
    * feat: update control gripper task to track potentiometer angle in global state
    * feat: increase DEAD_ZONE value to improve joystick sensitivity handling
    * feat: update controlGripperTask to use defined min/max potentiometer values for scaling
    * feat: enhance UART task with improved frame validation and detailed logging
    * feat: correct joystick axis reading order in controlXYAxisTask and use defined UART_BAUD in UART_TaskCreate
    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
    [XYstepperTask.c, main.c, switchModeTask.c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]
2025-12-14 Esp v2 (#19)
    * feat: enhance mode switching with server confirmation and error handling
    * feat: improve Wi-Fi connection handling and add watchdog functionality
    * feat: update potentiometer handling to improve value mapping and processing
    * feat: implement potentiometer change handling and broadcasting
    * feat: enhance logging system and update Wi-Fi configuration
    * feat: implement joystick data throttling and improve server communication
    * feat: optimize joystick data transmission frequency and enhance center position handling
    * feat: implement joystick center heartbeat and enhance server communication logic
    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
    [main.cpp]
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2026-02-02 Mainboard (#20)
    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
2026-02-04 fix: update gripper angle mapping and slider functionality
2026-02-06 fix: update RJ-45 pinout table to include PONCHO pin assignments
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2026-02-09 Pcb branch (#22)
    * fix: change ESP32 I/O pins
    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
    [Diseño esquematico Garra.kicad_pcb]
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
